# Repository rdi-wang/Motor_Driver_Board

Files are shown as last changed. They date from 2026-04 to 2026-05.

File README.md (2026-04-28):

# Motor_Driver_Board
PCB for A4988 Stepper Driver + Arduino Pico

Arduino Pico pins used:
    40 - VDD
    1 - DIR
    2 - STEP
    4 - MS3
    5 - MS2
    6 - MS1

A4988 specs
- Output capacity: 35V, +-2A
- Operating voltage: 8-35V
- Continuous current per phase: 1A
- Max current per phase: 2A
- Logic voltage: 3-5.5V

A4988 Step Control
    Values in order of: MS1, MS2, MS3
        LO, LO, LO: Full step
        HI, LO, LO: 1/2 step
        LO, HI, LO: 1/4 step
        HI, HI, LO: 1/8 step
        HI, HI, HI: 1/16 step

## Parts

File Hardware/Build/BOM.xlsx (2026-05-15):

Reference | Qty | Value | Footprint | JLCPCB Part | Manufacturer Part
C3 | 1 | 10u | Capacitor_SMD:C_1206_3216Metric | C13585 | CL31A106KBHNNNE
C4,C5,C6 | 3 | 47u | Capacitor_SMD:C_1206_3216Metric | C96123 | CL31A476MPHNNNE
C7,C8,C9 | 3 | 10n | Capacitor_SMD:C_0603_1608Metric | C57112 | 0603B103K500NT
D1 | 1 | SS34 | Diode_SMD:D_SMA | C8678 | SS34
L1 | 1 | FXL1040-680-M | Inductor_SMD:L_Sunlord_MWSA1005S | C475920 | FXL1040-680-M
R1,R2,R3,R4,R5,R6,R7,R8,R9 | 11 | 10K | Resistor_SMD:R_0603_1608Metric | C25804 | 0603WAF1002T5E
R10,R11 | 2 | 2.2K | Resistor_SMD:R_0603_1608Metric | C4190 | 0603WAF2201T5E
U1 | 1 | XL1509-5.0 | Package_SO:SOIC-8_3.9x4.9mm_P1.27mm | C61063 | XL1509-5.0E1

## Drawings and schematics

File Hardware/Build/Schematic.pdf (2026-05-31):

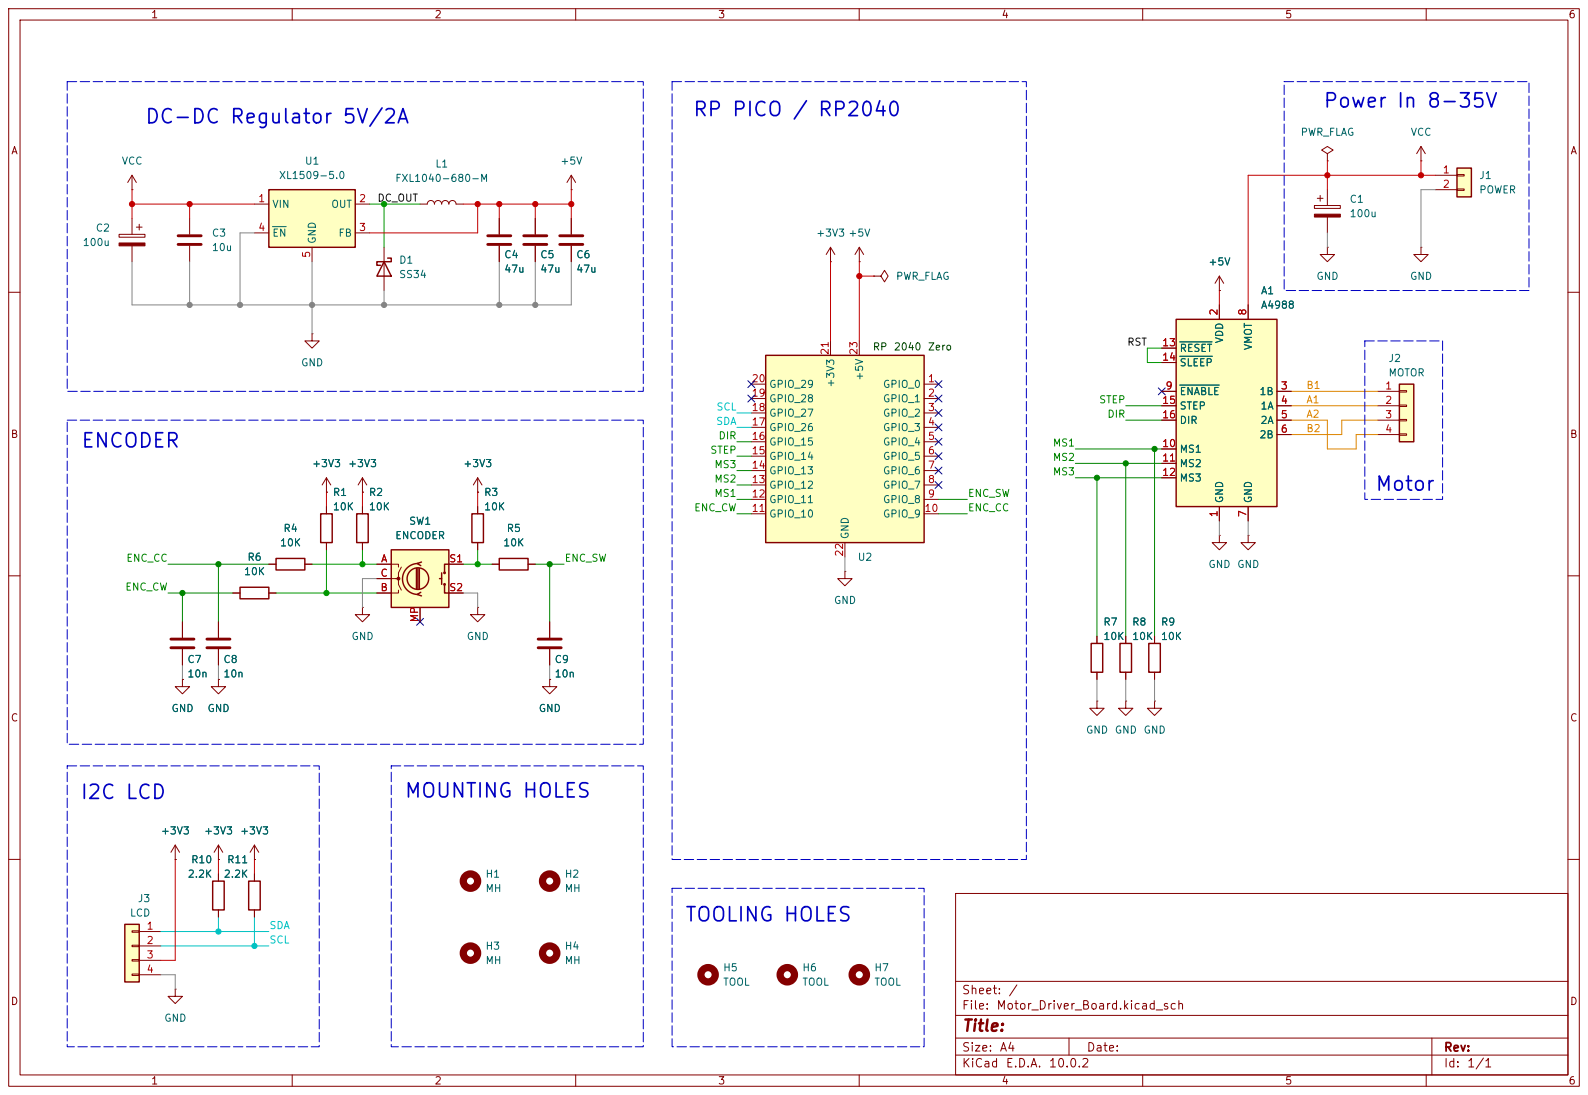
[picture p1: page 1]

Size: A4 | Rev:
KiCad E.D.A. 10.0.2 | Id: 1/1

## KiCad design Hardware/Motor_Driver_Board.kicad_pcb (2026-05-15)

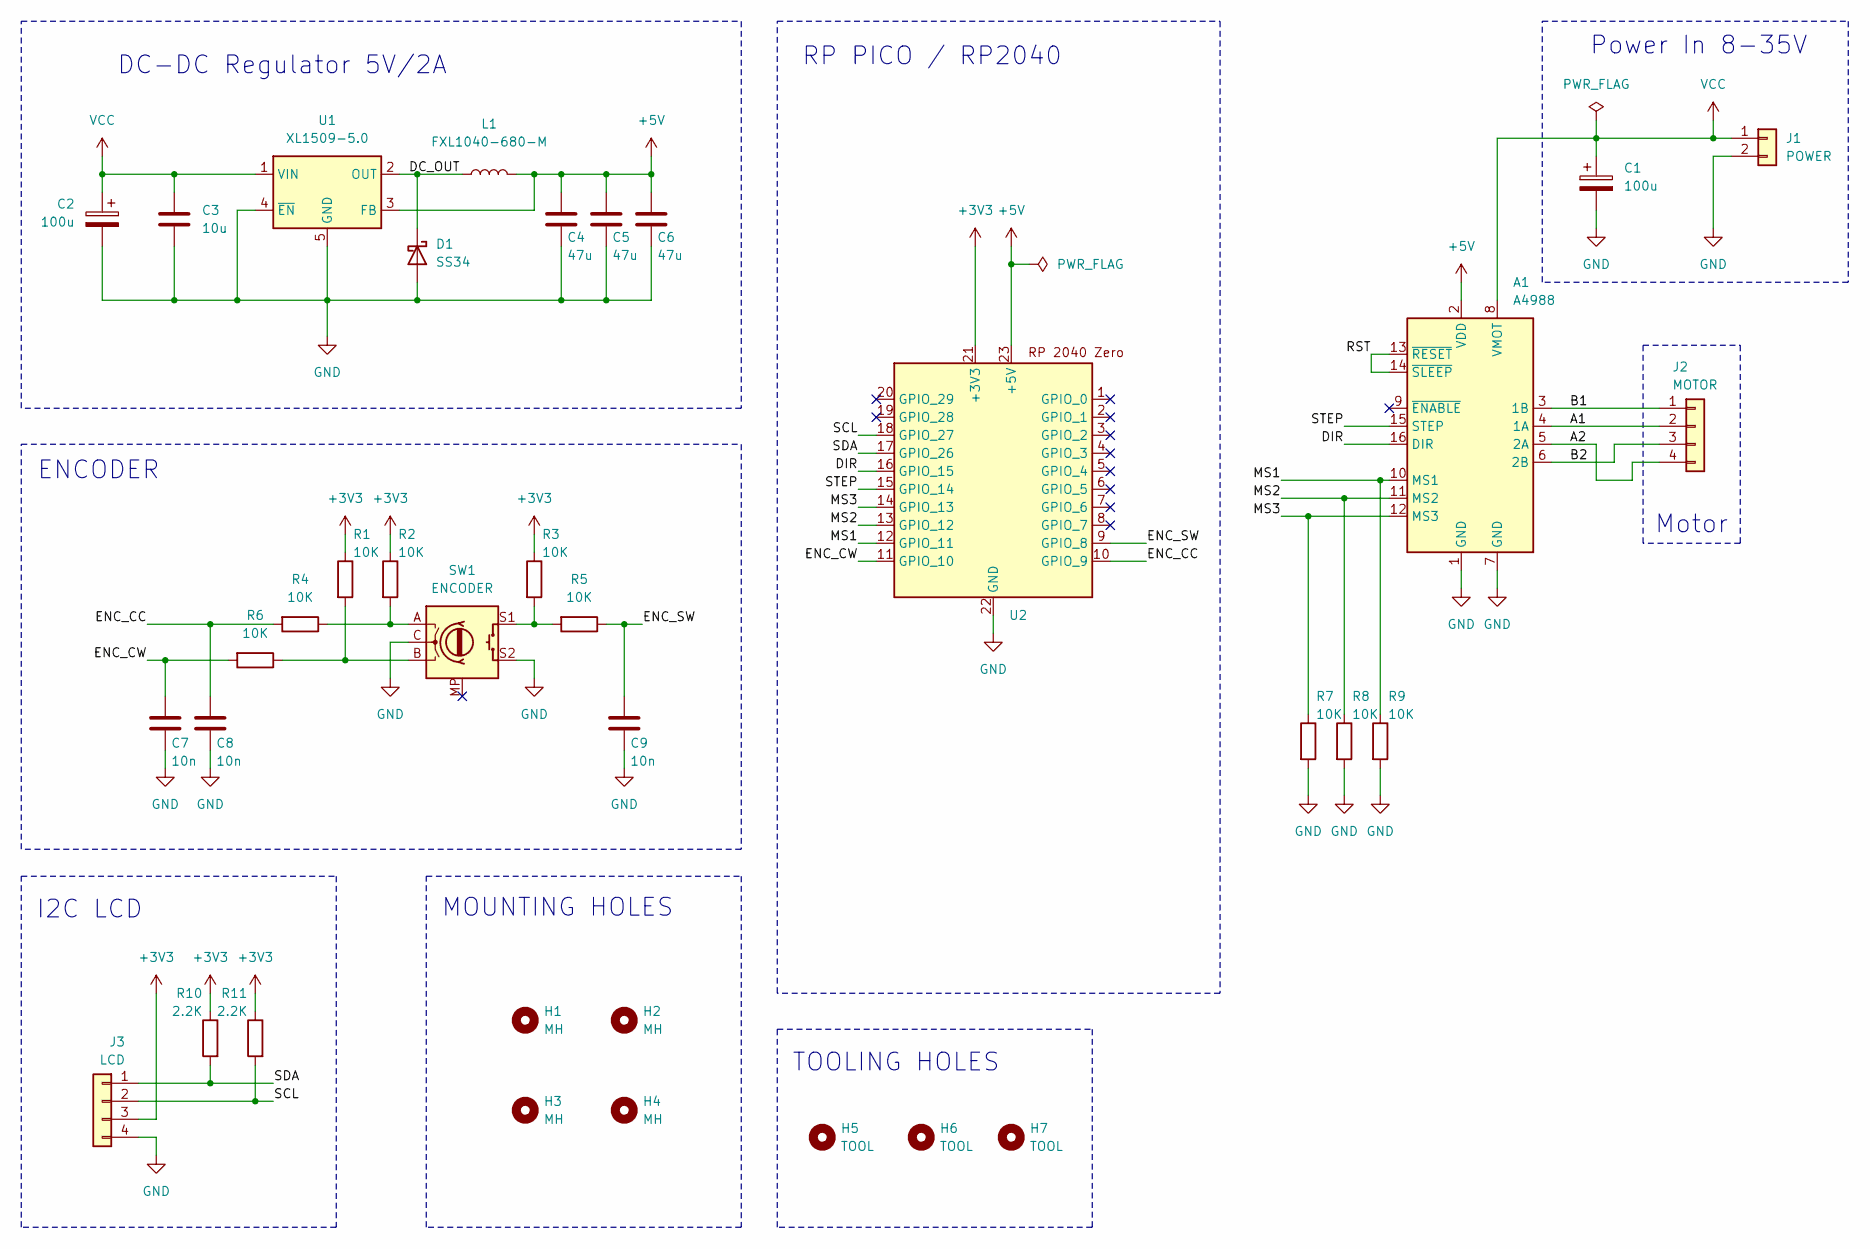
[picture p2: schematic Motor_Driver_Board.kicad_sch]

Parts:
A1: A4988; MODULE_A4988_STEPPER_MOTOR_DRIVER_CARRIER
C1, C2: 100u; CP_Radial_D8.0mm_P3.50mm; Manufacturer Part PA35V100M6x8; JLCPCB Part C46550435
C3: 10u; C_1206_3216Metric; Manufacturer Part CL31A106KBHNNNE; JLCPCB Part C13585
C4, C5, C6: 47u; C_1206_3216Metric; Manufacturer Part CL31A476MPHNNNE; JLCPCB Part C96123
C7, C8, C9: 10n; C_0603_1608Metric; Manufacturer Part 0603B103K500NT; JLCPCB Part C57112
D1: SS34; D_SMA; Manufacturer Part SS34; JLCPCB Part C8678
H1, H2, H3, H4: MH; MountingHole_3.2mm_M3
H5, H6, H7: TOOL; ToolingHole_1.152mm
J1: POWER; PinHeader_1x02_P2.54mm_Vertical; Manufacturer Part PZ254V-11-02P; JLCPCB Part C492401
J2: MOTOR; PinHeader_1x04_P2.54mm_Vertical; Manufacturer Part PZ254V-11-04P; JLCPCB Part C2691448
J3: LCD; PinSocket_1x04_P2.54mm_Vertical; Manufacturer Part PZ254V-11-04P; JLCPCB Part C2691448
L1: FXL1040-680-M; L_Sunlord_MWSA1005S; Manufacturer Part FXL1040-680-M; JLCPCB Part C475920
R1, R2, R3, R4, R5, R6, R7, R8, R9: 10K; R_0603_1608Metric; Manufacturer Part 0603WAF1002T5E; JLCPCB Part C25804
R10, R11: 2.2K; R_0603_1608Metric; Manufacturer Part 0603WAF1002T5E; JLCPCB Part C25804
SW1: ENCODER; RotaryEncoder_Alps_EC11E; Manufacturer Part EC11E18244AU; JLCPCB Part C202365
U1: XL1509-5.0; SOIC-8_3.9x4.9mm_P1.27mm; Manufacturer Part XL1509-5.0E1; JLCPCB Part C61063
U2: MODULE_RP2040-ZERO; Manufacturer Part RP2040-Zero; JLCPCB Part C5350143

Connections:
+3V3: J3.3, R1.1, R2.1, R3.1, R10.1, R11.1, U2.21 (+3V3)
+5V: A1.2 (VDD), C4.1, C5.1, C6.1, L1.2, U1.3 (FB), U2.23 (+5V)
/A1: A1.4 (1A), J2.2
/A2: A1.5 (2A), J2.4
/B1: A1.3 (1B), J2.1
/B2: A1.6 (2B), J2.3
/DC_OUT: D1.1 (K), L1.1, U1.2 (OUT)
/DIR: A1.16 (DIR), U2.16 (GPIO_15)
/ENC_CC: C8.1, R4.2, U2.10 (GPIO_9)
/ENC_CW: C7.1, R6.2, U2.11 (GPIO_10)
/ENC_SW: C9.1, R5.1, U2.9 (GPIO_8)
/MS1: A1.10 (MS1), R9.1, U2.12 (GPIO_11)
/MS2: A1.11 (MS2), R8.1, U2.13 (GPIO_12)
/MS3: A1.12 (MS3), R7.1, U2.14 (GPIO_13)
/RST: A1.13 (~RESET), A1.14 (~SLEEP)
/SCL: J3.2, R11.2, U2.18 (GPIO_27)
/SDA: J3.1, R10.2, U2.17 (GPIO_26)
/STEP: A1.15 (STEP), U2.15 (GPIO_14)
GND: A1.1 (GND), A1.7 (GND), C1.2, C2.2, C3.2, C4.2, C5.2, C6.2, C7.2, C8.2, C9.2, D1.2 (A), J1.2, J3.4, R7.2, R8.2, R9.2, SW1.C, SW1.S2, U1.4 (~EN), U1.5 (GND), U1.6 (GND), U1.7 (GND), U1.8 (GND), U2.22 (GND)
unnamed: R1.2, R6.1, SW1.B
unnamed: R2.2, R4.1, SW1.A
unnamed: R3.2, R5.2, SW1.S1
VCC: A1.8 (VMOT), C1.1, C2.1, C3.1, J1.1, U1.1 (VIN)

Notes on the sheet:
MOUNTING HOLES
TOOLING HOLES
I2C LCD
DC-DC Regulator 5V/2A
Motor
ENCODER
RP PICO / RP2040
Power In 8-35V

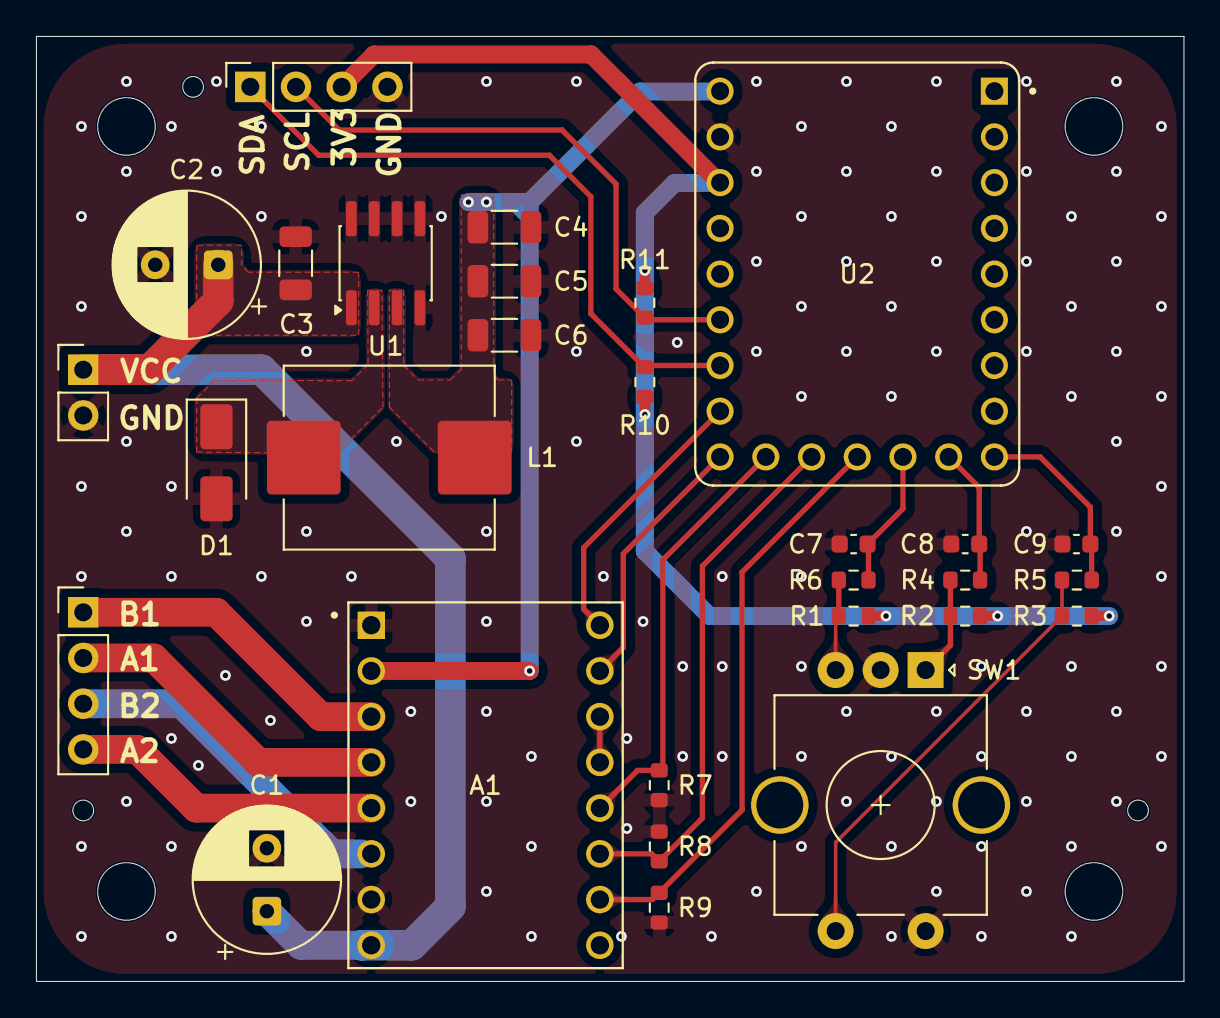
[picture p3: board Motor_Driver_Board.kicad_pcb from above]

Board: 2 copper layers, 63.8 x 52.5 mm, 36 parts (0 on the bottom side), 23 nets.

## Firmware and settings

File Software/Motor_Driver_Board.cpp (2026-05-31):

#include <string>
#include <cstring>
#include <math.h>

#include "pico/stdlib.h"
#include "hardware/i2c.h"

#include "ssd1306_font.h"

// Display dimension definitions
#define SSD1306_HEIGHT  32
#define SSD1306_WIDTH   128

#define SSD1306_I2C_ADDR 0x3C
#define SSD1306_I2C_CLK 400

// Command definitions
#define SSD1306_SET_MEM_MODE        0x20
#define SSD1306_SET_COL_ADDR        0x21
#define SSD1306_SET_PAGE_ADDR       0x22
#define SSD1306_SET_HORIZ_SCROLL    0x26
#define SSD1306_SET_SCROLL          0x2E

#define SSD1306_SET_DISP_START_LINE 0x40

#define SSD1306_SET_CONTRAST        0x81
#define SSD1306_SET_CHARGE_PUMP     0x8D

#define SSD1306_SET_SEG_REMAP           0xA0
#define SSD1306_SET_ENTIRE_ON           0xA4
#define SSD1306_SET_ALL_ON              0xA5
#define SSD1306_SET_NORM_DISP           0xA6
#define SSD1306_SET_INV_DISP            0xA7
#define SSD1306_SET_MUX_RATIO           0xA8
#define SSD1306_SET_DISP                0xAE
#define SSD1306_SET_COM_OUT_DIR         0xC0
#define SSD1306_SET_COM_OUT_DIR_FLIP    0xC0

#define SSD1306_SET_DISP_OFFSET     0xD3
#define SSD1306_SET_DISP_CLK_DIV    0xD5
#define SSD1306_SET_PRECHARGE       0xD9
#define SSD1306_SET_COM_PIN_CFG     0xDA
#define SSD1306_SET_VCOM_DESEL      0xDB

#define SSD1306_PAGE_HEIGHT 8
#define SSD1306_NUM_PAGES   (SSD1306_HEIGHT / SSD1306_PAGE_HEIGHT)
#define SSD1306_BUF_LEN     (SSD1306_NUM_PAGES * SSD1306_WIDTH)

#define SSD1306_WRITE_MODE  0xFE
#define SSD1306_READ_MODE   0xFF

// I2C port definitions
#define I2C_PORT i2c1
#define I2C_SDA 26
#define I2C_SCL 27

struct render_area {
    uint8_t start_col;
    uint8_t end_col;
    uint8_t start_page;
    uint8_t end_page;

    int buflen;
}frame_area;

uint8_t buffer[SSD1306_BUF_LEN];

void calc_render_area_buflen(struct render_area *area) {
    area->buflen = (area->end_col - area->start_col + 1) * (area->end_page - area->start_page + 1);
}

void SSD1306_send_cmd(uint8_t cmd) {
    uint8_t buf[2] = {0x80, cmd};
    i2c_write_blocking(I2C_PORT, SSD1306_I2C_ADDR, buf, 2, false);
}

void SSD1306_send_cmd_list(uint8_t *buf, int num) {
    for (int i=0;i<num;i++)
        SSD1306_send_cmd(buf[i]);
}

void SSD1306_send_buf(uint8_t buf[], int buflen) {
    uint8_t temp_buf[buflen + 1];

    temp_buf[0] = 0x40;
    memcpy(temp_buf+1, buf, buflen);

    i2c_write_blocking(I2C_PORT, SSD1306_I2C_ADDR, temp_buf, buflen + 1, false);
}

void render(uint8_t *buf, struct render_area *area) {
    uint8_t cmds[] = {
        SSD1306_SET_COL_ADDR,
        area->start_col,
        area->end_col,
        SSD1306_SET_PAGE_ADDR,
        area->start_page,
        area->end_page
    };

    SSD1306_send_cmd_list(cmds, count_of(cmds));
    SSD1306_send_buf(buf, area->buflen);
}

void SSD1306_init() {
    i2c_init(I2C_PORT, SSD1306_I2C_CLK * 1000);
    gpio_set_function(I2C_SDA, GPIO_FUNC_I2C);
    gpio_set_function(I2C_SCL, GPIO_FUNC_I2C);

    uint8_t cmds[] = {
        SSD1306_SET_DISP,               // set display off
        /* memory mapping */
        SSD1306_SET_MEM_MODE,           // set memory address mode 0 = horizontal, 1 = vertical, 2 = page
        0x00,                           // horizontal addressing mode
        /* resolution and layout */
        SSD1306_SET_DISP_START_LINE,    // set display start line to 0
        SSD1306_SET_SEG_REMAP | 0x01,   // set segment re-map, column address 127 is mapped to SEG0
        SSD1306_SET_MUX_RATIO,          // set multiplex ratio
        SSD1306_HEIGHT - 1,             // Display height - 1
        SSD1306_SET_COM_OUT_DIR | 0x08, // set COM output scan direction. Scan from bottom up, COM[N-1] to COM0
        SSD1306_SET_DISP_OFFSET,        // set display offset
        0x00,                           // no offset
        SSD1306_SET_COM_PIN_CFG,        // set COM pins hardware configuration. Board specific magic number.
                                        // 0x02 Works for 128x32, 0x12 Possibly works for 128x64. Other options 0x22, 0x32
#if ((SSD1306_WIDTH == 128) && (SSD1306_HEIGHT == 32))
        0x02,
#elif ((SSD1306_WIDTH == 128) && (SSD1306_HEIGHT == 64))
        0x12,
#else
        0x02,
#endif
        /* timing and driving scheme */
        SSD1306_SET_DISP_CLK_DIV,       // set display clock divide ratio
        0x80,                           // div ratio of 1, standard freq
        SSD1306_SET_PRECHARGE,          // set pre-charge period
        0xF1,                           // Vcc internally generated on our board
        SSD1306_SET_VCOM_DESEL,         // set VCOMH deselect level
        0x30,                           // 0.83xVcc
        /* display */
        SSD1306_SET_CONTRAST,           // set contrast control
        0xFF,
        SSD1306_SET_ENTIRE_ON,          // set entire display on to follow RAM content
        SSD1306_SET_NORM_DISP,           // set normal (not inverted) display
        SSD1306_SET_CHARGE_PUMP,        // set charge pump
        0x14,                           // Vcc internally generated on our board
        SSD1306_SET_SCROLL | 0x00,      // deactivate horizontal scrolling if set. This is necessary as memory writes will corrupt if scrolling was enabled
        SSD1306_SET_DISP | 0x01, // turn display on
    };

    SSD1306_send_cmd_list(cmds, count_of(cmds));

    frame_area = {
        start_col: 0,
        end_col : SSD1306_WIDTH - 1,
        start_page : 0,
        end_page : SSD1306_NUM_PAGES - 1
    };

    calc_render_area_buflen(&frame_area);

    memset(buffer, 0, SSD1306_BUF_LEN);
    render(buffer, &frame_area);
}

void SSD1306_scroll(bool on) {
    uint8_t scroll = SSD1306_SET_SCROLL | (on ? uint8_t{1} : uint8_t{0});

    uint8_t cmds[] = {
        SSD1306_SET_HORIZ_SCROLL | 0x00,
        0x00, // dummy byte
        0x00, // start page 0
        0x00, // time interval
        SSD1306_NUM_PAGES - 1, // end page
        0x00, // dummy byte
        0xFF, // dummy byte
        scroll // Start/stop scrolling
    };

    SSD1306_send_cmd_list(cmds, count_of(cmds));
}

static void SetPixel(uint8_t *buf, int x,int y, bool on) {
    assert(x >= 0 && x < SSD1306_WIDTH && y >=0 && y < SSD1306_HEIGHT);

    const int BytesPerRow = SSD1306_WIDTH ; // x pixels, 1bpp, but each row is 8 pixel high, so (x / 8) * 8

    int byte_idx = (y / 8) * BytesPerRow + x;
    uint8_t byte = buf[byte_idx];

    if (on)
        byte |=  1 << (y % 8);
    else
        byte &= ~(1 << (y % 8));

    buf[byte_idx] = byte;
}

static void DrawLine(uint8_t *buf, int x0, int y0, int x1, int y1, bool on) {

    int dx =  abs(x1-x0);
    int sx = x0<x1 ? 1 : -1;
    int dy = -abs(y1-y0);
    int sy = y0<y1 ? 1 : -1;
    int err = dx+dy;
    int e2;

    while (true) {
        SetPixel(buf, x0, y0, on);
        if (x0 == x1 && y0 == y1)
            break;
        e2 = 2*err;

        if (e2 >= dy) {
            err += dy;
            x0 += sx;
        }
        if (e2 <= dx) {
            err += dx;
            y0 += sy;
        }
    }
}

static inline int GetFontIndex(uint8_t ch) {
    if (ch >= 'A' && ch <='Z') {
        return  ch - 'A' + 1;
    }
    else if (ch >= '0' && ch <='9') {
        return  ch - '0' + 27;
    }
    else return  0; // Not got that char so space.
}

static void WriteChar(uint8_t *buf, int16_t x, int16_t y, uint8_t ch) {
    if (x > SSD1306_WIDTH - 8 || y > SSD1306_HEIGHT - 8)
        return;

    y = y/8;

    ch = toupper(ch);
    int idx = GetFontIndex(ch);
    int fb_idx = y * 128 + x;

    for (int i=0;i<8;i++) {
        buf[fb_idx++] = font[idx * 8 + i];
    }
}

static void WriteString(uint8_t *buf, int16_t x, int16_t y, const char *str) {
    if (x > SSD1306_WIDTH - 8 || y > SSD1306_HEIGHT - 8)
        return;

    while (*str) {
        WriteChar(buf, x, y, *str++);
        x+=8;
    }
}

// Stepper driver pin definitions
#define STP_PIN 14
#define DIR_PIN 15
#define MS1_PIN 11
#define MS2_PIN 12
#define MS3_PIN 13

// Steps per rotation for the NEMA17
#define STEPS_PER_REV 200.0f
#define MAX_RPM       600.0f

typedef enum {
    MICROSTEP_FULL      = 1,
    MICROSTEP_HALF      = 2,
    MICROSTEP_QUARTER   = 4,
    MICROSTEP_EIGHTH    = 8,
    MICROSTEP_SIXTEENTH = 16
} microstep_mode_t;

static uint32_t step_delay_us = 0;
static microstep_mode_t current_microstep = MICROSTEP_FULL;

static float current_speed_rpm = 0.0f;
static float target_speed_rpm  = 0.0f;

static float accel_rpm_per_s = 120.0f;

static absolute_time_t last_ramp_update;

static uint32_t rpm_to_step_delay_us(float rpm, microstep_mode_t microstep) {
    if (rpm <= 0.0f) {
        return 0;
    }

    if (rpm > MAX_RPM) {
        rpm = MAX_RPM;
    }

    float steps_per_rev = STEPS_PER_REV * (float)microstep;
    float steps_per_sec = (rpm * steps_per_rev) / 60.0f;

    if (steps_per_sec < 1.0f) {
        steps_per_sec = 1.0f;
    }

    return (uint32_t)(1000000.0f / steps_per_sec);
}

static void stepper_apply_speed(void) {
    step_delay_us = rpm_to_step_delay_us(current_speed_rpm, current_microstep);
}

static void stepper_set_microstep(microstep_mode_t mode) {
    current_microstep = mode;

    switch (mode) {
        case MICROSTEP_FULL:
            gpio_put(MS1_PIN, 0);
            gpio_put(MS2_PIN, 0);
            gpio_put(MS3_PIN, 0);
            break;

        case MICROSTEP_HALF:
            gpio_put(MS1_PIN, 1);
            gpio_put(MS2_PIN, 0);
            gpio_put(MS3_PIN, 0);
            break;

        case MICROSTEP_QUARTER:
            gpio_put(MS1_PIN, 0);
            gpio_put(MS2_PIN, 1);
            gpio_put(MS3_PIN, 0);
            break;

        case MICROSTEP_EIGHTH:
            gpio_put(MS1_PIN, 1);
            gpio_put(MS2_PIN, 1);
            gpio_put(MS3_PIN, 0);
            break;

        case MICROSTEP_SIXTEENTH:
            gpio_put(MS1_PIN, 1);
            gpio_put(MS2_PIN, 1);
            gpio_put(MS3_PIN, 1);
            break;
    }

    /* Same shaft RPM, new pulse/rev => recompute delay */
    stepper_apply_speed();
}

static void stepper_init(void) {
    gpio_init(STP_PIN);
    gpio_set_dir(STP_PIN, GPIO_OUT);
    gpio_put(STP_PIN, 0);

    gpio_init(DIR_PIN);
    gpio_set_dir(DIR_PIN, GPIO_OUT);
    gpio_put(DIR_PIN, 0);

    gpio_init(MS1_PIN);
    gpio_set_dir(MS1_PIN, GPIO_OUT);

    gpio_init(MS2_PIN);
    gpio_set_dir(MS2_PIN, GPIO_OUT);

    gpio_init(MS3_PIN);
    gpio_set_dir(MS3_PIN, GPIO_OUT);

    current_speed_rpm   = 0.0f;
    target_speed_rpm    = 0.0f;
    step_delay_us       = 0;

    stepper_set_microstep(MICROSTEP_FULL);
    last_ramp_update = get_absolute_time();
}

static void stepper_set_direction(bool clockwise) {
    gpio_put(DIR_PIN, clockwise ? 1 : 0);
}

static void stepper_set_speed_rpm(float rpm) {
    if (rpm < 0.0f) {
        rpm = 0.0f;
    }

    if (rpm > MAX_RPM) {
        rpm = MAX_RPM;
    }

    target_speed_rpm = rpm;
}

static void stepper_set_acceleration_rpm(float rpm_per_s) {
    if (rpm_per_s < 1.0f) {
        rpm_per_s = 1.0f;
    }

    accel_rpm_per_s = rpm_per_s;
}

static void stepper_update_speed_ramp(void) {
    absolute_time_t now = get_absolute_time();
    int64_t dt_us = absolute_time_diff_us(last_ramp_update, now);
    last_ramp_update = now;

    if (dt_us <= 0) {
        return;
    }

    float dt_s = (float)dt_us / 1000000.0f;
    float max_delta_rpm = accel_rpm_per_s * dt_s;
    float error = target_speed_rpm - current_speed_rpm;

    if (fabsf(error) <= max_delta_rpm) {
        current_speed_rpm = target_speed_rpm;
    } else if (error > 0.0f) {
        current_speed_rpm += max_delta_rpm;
    } else {
        current_speed_rpm -= max_delta_rpm;
    }

    stepper_apply_speed();
}

static void stepper_run(void) {
    stepper_update_speed_ramp();

    if (step_delay_us == 0) {
        sleep_us(1000);
        return;
    }

    gpio_put(STP_PIN, 1);
    sleep_us(2);
    gpio_put(STP_PIN, 0);

    if (step_delay_us > 2) {
        sleep_us(step_delay_us - 2);
    }
}

// Define the type of edge trigger
#define GPIO_IRQ_EDGE GPIO_IRQ_EDGE_RISE

// Encoder pin definitions
#define ENC_CC 9
#define ENC_CW 10
#define ENC_SW 8

void update_display() {
    std::string step_mode;

    switch (current_microstep) {
        case MICROSTEP_FULL:
            step_mode = "Full";
            break;
        case MICROSTEP_HALF:
            step_mode = "Half";
        break;
        case MICROSTEP_QUARTER:
            step_mode = "Quarter";
        break;
        case MICROSTEP_EIGHTH:
            step_mode = "Eighth";
        break;
        case MICROSTEP_SIXTEENTH:
            step_mode = "Sixteenth";
        break;
        default:
            step_mode = "Error";
            break;
    }

    std::string text[] = { "STEPPER DRIVER", "Mode: " + step_mode, "Speed: " + std::to_string((int)target_speed_rpm) };

    memset(buffer, 0, SSD1306_BUF_LEN);
    render(buffer, &frame_area);

    int y = 0;
    for (uint i = 0 ; i < count_of(text); i++) {
        WriteString(buffer, 5, y, text[i].c_str());
        y+=8;
    }
    render(buffer, &frame_area);

    printf("Update display!\n");
}

void gpio_callback(uint gpio, uint32_t events) {
    // Check for clockwise operartion
    if (gpio == ENC_CW) {
        if (!gpio_get(ENC_CC)){
            stepper_set_speed_rpm(target_speed_rpm - 10.0f);

            update_display();
        }

        return;
    }

    // Check for counterclockwise operartion
    if (gpio == ENC_CC) {
        if (!gpio_get(ENC_CW)){
            stepper_set_speed_rpm(target_speed_rpm + 10.0f);

            update_display();
        }

        return;
    }

    // Check for button operation
    if (gpio == ENC_SW) {
        switch (current_microstep) {
            case MICROSTEP_FULL:
                stepper_set_microstep(MICROSTEP_HALF);
                break;
            case MICROSTEP_HALF:
                stepper_set_microstep(MICROSTEP_QUARTER);
            break;
            case MICROSTEP_QUARTER:
                stepper_set_microstep(MICROSTEP_EIGHTH);
            break;
            case MICROSTEP_EIGHTH:
                stepper_set_microstep(MICROSTEP_SIXTEENTH);
            break;
            case MICROSTEP_SIXTEENTH:
                stepper_set_microstep(MICROSTEP_FULL);
            break;
            default:
                stepper_set_microstep(MICROSTEP_FULL);
                break;
        }

        stepper_set_speed_rpm(target_speed_rpm);

        update_display();

        return;
    }
}

static void set_gpio_handlers() {
    gpio_init(ENC_CC);
    gpio_set_dir(ENC_CC, GPIO_IN);

    gpio_init(ENC_CW);
    gpio_set_dir(ENC_CW, GPIO_IN);

    gpio_init(ENC_SW);
    gpio_set_dir(ENC_SW, GPIO_IN);

    gpio_set_irq_enabled_with_callback(ENC_CC, GPIO_IRQ_EDGE, true, gpio_callback);
    gpio_set_irq_enabled_with_callback(ENC_CW, GPIO_IRQ_EDGE, true, gpio_callback);
    gpio_set_irq_enabled_with_callback(ENC_SW, GPIO_IRQ_EDGE, true, gpio_callback);
}

int main() {
    stdio_init_all();

    SSD1306_init();

    set_gpio_handlers();

    stepper_init();

    stepper_set_direction(true);
    stepper_set_microstep(MICROSTEP_HALF);
    stepper_set_speed_rpm(60.0f);

    update_display();

    while (1) {
        stepper_run();
    }
}

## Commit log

2026-04-28 Created on 4/29/2026
    Built initial schematic and PCB layout for A4988 motor controller board
    Updated readme.txt
    Updated gitignore
    [Motor_Driver_Board.kicad_pcb, Motor_Driver_Board.kicad_sch]
2026-04-28 Re-included .kicad_pro files
    Edited .gitignore to re-include .kicad_pro files, required project file
2026-04-29 Shcematic and layout
    Updated the schematic.
    Updated the layout.
    [Motor_Driver_Board.kicad_pcb, Motor_Driver_Board.kicad_sch]
2026-04-30 Switch to RP2040-Zero
    Switched controller to RP2040-Zero to save space, schematic updated.
    PCB layout in progress
    [Motor_Driver_Board.kicad_pcb, Motor_Driver_Board.kicad_sch]
2026-04-30 Added RP2040-Zero Microcontroller
    Switched previous Pi Pico to RP2040-Zero by Waveshare to reduce overall board size. Layout complete, via hatching still required
    [Motor_Driver_Board.kicad_pcb, Motor_Driver_Board.kicad_sch]
2026-04-30 Update Motor_Driver_Board.kicad_pcb
    Small update with dimensions shown in user drawings
    [Motor_Driver_Board.kicad_pcb]
2026-05-01 Layout revision
    Updated the schematic pinout for the RP2040.
    Updated the PCB layout.
    Rotated the motor driver.
    Moved the motor header to the side of the board.
    Added via stitching.
    Removed vias in pads.
    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
    [Motor_Driver_Board.kicad_pcb, Motor_Driver_Board.kicad_sch]
2026-05-01 PCB layout and models
    Updated the models for the MCU, motor driver and encoder.
    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
    [Motor_Driver_Board.kicad_pcb, Motor_Driver_Board.kicad_sch]
2026-05-04 Build outputs
    Added the intial build files.
    Added the part numbers for all components.
    [BOM.xlsx, Motor_Driver_Board.kicad_pcb, Motor_Driver_Board.kicad_sch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]
2026-05-04 Silkscreen notes
    Added some notes to the silkscreen layer.
    [Motor_Driver_Board.kicad_pcb]
2026-05-04 Footprints
    Updated the footprint for the bulk capacitors.
    [Motor_Driver_Board.kicad_pcb, Motor_Driver_Board.kicad_sch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]
2026-05-04 Tooling and silkscreen
    Updated the silkscreen.
    Added tooling holes for the assembly service.
    [Motor_Driver_Board.kicad_pcb, Motor_Driver_Board.kicad_sch]
2026-05-15 Structure and software
    Updated the project structure.
    Added an initial software for the board.
    Fixed minor errors on the PCB.
    [BOM.xlsx, Motor_Driver_Board.kicad_pcb, Motor_Driver_Board.kicad_sch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]
2026-05-31 Schematic and acceleration
    Added an schematic of the board.
    Added an acceleration algorithm to the stepper code.
